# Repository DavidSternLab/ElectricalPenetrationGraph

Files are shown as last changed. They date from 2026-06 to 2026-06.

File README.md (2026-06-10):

# EPG Rig Redesign

An open, modern redesign of the Electrical Penetration Graph (EPG) recording rig —
new hardware, firmware, and software — to replace the commercial **Giga-8dd**
(EPG Systems EU / W.F. Tjallingii). Used to record stylet-penetration / feeding
behavior of the pea aphid *Acyrthosiphon pisum*.

## Goals

1. **Improve temporal resolution** of sampling (original: 14-bit ADC @ 100 Hz default).
2. **Reduce production cost.**
3. **Simplify construction.**
4. **Automate voltage-drift correction** — the electrode-potential drift currently
   corrected by hand via the supplied voltage (Vs). An auto-detect/correct in firmware/software.
5. **Cross-platform software** — original Stylet+ is Windows-only and needs custom
   USB/COM/ActiveX drivers.

## Status

Early design phase — working through architecture decisions interactively.
See [docs/design-log.md](docs/design-log.md) for locked decisions and rationale.

## Document index

- [docs/design-log.md](docs/design-log.md) — decision log (what's locked + why).
- [docs/system-architecture.md](docs/system-architecture.md) — consolidated block diagram
  + signal chain as decided so far.
- [docs/noise-bandwidth-budget.md](docs/noise-bandwidth-budget.md) — quantitative noise &
  bandwidth analysis → gain, ADC, and the layout-critical input-capacitance spec.
- [docs/protocol-and-data-format.md](docs/protocol-and-data-format.md) — USB device↔host
  protocol + HDF5 recording format (draft v0.1).
- [docs/original-circuit-reference.md](docs/original-circuit-reference.md) — facts
  extracted from the Giga-8dd manuals (the circuit we're modernizing).
- [docs/conversation-log.md](docs/conversation-log.md) — chronological narrative of
  the design discussions.

## Folders

- `docs/` — design docs and decision records.
- `hardware/` — [single-channel-schematic.md](hardware/single-channel-schematic.md) (draft v0.1,
  SPICE-verified), [pcb-layout.md](hardware/pcb-layout.md) (layout spec / hand-off);
  `hardware/sim/` ngspice netlist; `hardware/netlist/` (ERC-checked netlist + generated
  `single_channel.kicad_sch` with footprints + SVG/PDF); `hardware/pcb/` (pre-placed
  `single_channel.kicad_pcb`, custom `.kicad_dru`, board render).
- `firmware/` — RP2040 firmware: portable C protocol (host-tested + interop-verified vs the
  Python codec) + Arduino app skeleton.
- `firmware/` — MCU firmware (to come).
- `software/` — cross-platform acquisition + analysis app, Python/pyqtgraph (to come).

## Source material

Original vendor documentation lives one level up in `../Giga_rig_manuals/`
(start with `Measuring principles.pdf`; differential probe circuit is Appendix 5 /
Fig 13B of `Manual-Giga-8dd 20.pdf`). The original Windows software in
`../original_rig_software/` is distributed only as `.exe` installers, so the Stylet+
data file format is not recoverable from it — we will define our own open format.

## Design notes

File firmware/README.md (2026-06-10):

# EPG rig — RP2040 firmware

Device-side firmware. The protocol layer is **portable C, shared with the host and
unit-tested on this machine**; the RP2040 application (USB CDC + ADC/DAC/relay drivers +
Vs servo) sits on top.

```
firmware/
  proto/         epg_proto.{h,c}   portable protocol codec (COBS+CRC, builders, parser)
  test/          test_proto.c + interop_test.py + Makefile   (host-compiled, runnable now)
  src/           RP2040 app: main.cpp, ads131m08.{h,cpp}, dac8568.{h,cpp}, board.h
  platformio.ini build/flash config (arduino-pico / earlephilhower core)
```

## Status
- **`proto/` + `test/`: built and verified on the host.** `make check` runs the C
  selftest; `make interop` proves the C codec and the Python host codec
  (`software/epgrig`) are **byte-for-byte compatible** in both directions. So when this
  firmware runs, it talks to the existing host GUI unchanged.
- **`src/`: a coherent skeleton, NOT yet hardware-tested.** The ADS131M08/DAC8568 register
  sequences and the relay/servo scaling are marked `TODO: verify vs datasheet`. It will not
  have been compiled in this environment (needs the RP2040 toolchain / PlatformIO).

## Protocol tests (run now, no hardware)
```bash
cd test
make check       # C selftest: COBS / CRC / i24 / frame / parser-resync
make interop     # cross-language: C <-> Python wire compatibility
```

## Build & flash the firmware (with hardware)
```bash
# install PlatformIO (pip install platformio), then:
pio run                 # compile
pio run -t upload       # flash a Pico/RP2040 over USB
pio device monitor      # (optional) serial monitor
```
Then point the host app at the serial port (replace the mock with a pyserial transport).

## Main loop (src/main.cpp)
On ADC **DRDY**: read 8 channels → run the keep-in-range **Vs servo** (D11) → append to the
current block. Every `BLOCK_MS` (default 50 ms) a **SAMPLES** frame is flushed. Host commands
(GET_INFO / CONFIGURE / START / STOP / SET_VS / SET_RI / CAL_PULSE / SERVO / PING) are parsed
from USB; **every state change emits a sample-stamped EVENT**, so recordings stay
reconstructable exactly as the format (D14) requires.

## To finish (hardware bring-up)
- ADS131M08 register init (CLOCK/MODE/GAIN/OSR for the selected rate) + CRC handling.
- DAC8568 reference-enable + Vs code↔volts calibration; servo step gain.
- 74HC595 latching-relay set/reset pulse for Ri (1 GΩ/10 TΩ) per channel.
- Pin map in `board.h` vs the actual PCB.

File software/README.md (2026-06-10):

# epgrig — host software (Python)

Cross-platform acquisition + analysis for the redesigned EPG rig. Implements the
device↔host protocol and HDF5 recording format in [../docs/protocol-and-data-format.md](../docs/protocol-and-data-format.md),
and ships an **in-process mock device** so the entire pipeline runs and is tested
**before any hardware exists**.

## Layout
```
epgrig/
  protocol.py     COBS+CRC framing + message codecs   (pure stdlib — always importable)
  mock_device.py  synthetic device: aphid-like waveforms, electrode drift, Vs servo
  acquisition.py  parse device frames -> recorder + live callbacks (transport-agnostic)
  recorder.py     incremental crash-safe HDF5 writer
  reader.py       HDF5 reader + signal reconstruction (codes->volts, applied-Vs)
  dsp.py          display-side detrend (high-pass) — view only, never recorded
  gui.py          live pyqtgraph display (optional Qt)
scripts/
  record_mock.py  headless end-to-end demo: mock -> frames -> HDF5 -> reconstruct
  run_gui.py      launch the live GUI against the mock
tests/            protocol + pipeline tests (run with no hardware)
```

## Quick start
```bash
pip install -r requirements.txt          # numpy + h5py minimum; Qt only for the GUI

# headless end-to-end (no hardware, no Qt):
python scripts/record_mock.py /tmp/epg.h5 --seconds 30 --rate 1000

# tests:
python tests/test_protocol.py            # pure stdlib
python tests/test_pipeline.py            # needs numpy + h5py
# (or: python -m pytest)

# live GUI against the mock (needs pyqtgraph + a Qt binding):
python scripts/run_gui.py --rate 1000
```

## Design notes
- **Protocol layer is dependency-free** (stdlib only) so framing is trivially testable and
  portable; numpy/h5py are only needed for the data path, Qt only for the GUI.
- **Reconstructability:** recordings store raw 24-bit codes + a timestamped event log; the
  reader recovers input-referred volts and the applied-Vs trace, so the true signal is
  recoverable even though the keep-in-range servo nudges Vs during recording.
- **Real hardware later** drops in behind the same protocol: replace the mock's byte stream
  with a `pyserial` port (USB CDC). Nothing else changes.

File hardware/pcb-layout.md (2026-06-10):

# PCB layout specification — single-channel probe-head daughtercard

**Hand-off to the KiCad layout engineer.** The electrical design is fixed and verified
(schematic `netlist/single_channel.kicad_sch` with footprints; SPICE in `sim/`; ERC clean).
This board is a **femtoampere electrometer front end** — *layout is the design*. The rules
below are not style preferences; violating the input-node ones will sink the instrument's
performance. Do **not** autoroute the input section.

## What's provided vs. what you do
- **Provided:** schematic with footprints assigned; a starting board `pcb/single_channel.kicad_pcb`
  (23 footprints pre-placed with the intended signal flow, 60×40 mm outline, 4 layers) and a
  `pcb/single_channel.kicad_dru` with custom rules.
- **You do:** *Update PCB from Schematic* (pulls nets/ratsnest — the schematic carries
  footprints), refine placement (the starting board has ~41 courtyard/silk/edge DRC items
  from tight auto-placement — spread/rotate to clear), implement the guard scheme below,
  route, and get a clean DRC. Replace the PLACEHOLDER footprints (J2 Lemo/ODU, K1 latching
  reed relay, optionally U3 exact LFCSP) with the real vendor footprints.

## Board & stackup
- Small daughtercard, ~50–60 × 35–40 mm (refine to fit the probe-head enclosure + BNC + Lemo).
- **4-layer**, suggested: `L1 Signal / L2 Ground / L3 Power(±5) / L4 Signal`.
- **Exception (critical):** *no ground or power copper under the high-impedance input node*
  (see below) — pour reliefs / keep-outs there on all layers.

## The make-or-break input section (node M = J1→A1.INP; RI_MID; A2.INP/S)
This is the ≤1 pF, sub-fA-leakage region (validated: f₋₃dB = 1/(2π·(Rbe‖Ri)·Cin), so Cin
sets bandwidth — D13/D16).
1. **Minimize Cin:** A1 immediately adjacent to J1; M trace as short and thin as possible;
   **no vias** on M; **no copper plane under M** on any layer (cut out / keep-out). Keep RI
   and K1 contacts right at the node.
2. **Guard ring:** surround M (and the A1 +input pin/trace, RI, K1 contacts) with a guard
   trace driven by **A1.GUARD**; do the same for A2.INP using **A2.GUARD**. The guard
   follows the high-Z trace on the component layer *and* is mirrored on the layer beneath
   (guard "box"), connected only to the GUARD pin — never to ground. This bootstraps stray
   capacitance and intercepts surface-leakage currents.
3. **Surface leakage:** consider a **milled slot/moat** in the PCB around the M node to break
   surface conduction; specify **solder-mask opening** over the guard region and **conformal
   coat** (or PTFE) after a thorough clean. Use **no-clean-free** assembly or wash + bake;
   the input area must be contamination-free (fingerprints = picoamps).
4. **The ADA4530-1 guard pins** (A1, A2) must connect *only* to their guard rings.

## Net classes (set in Board Setup → Net Classes)
| Class | Nets | Trace | Clearance | Notes |
|---|---|---|---|---|
| **HighZ** | M, RI_MID | thin (~0.2 mm), no via | ≥0.6 mm to other copper | guarded; no plane under |
| **Guard** | GUARD1, GUARD2 | ~0.3 mm | hugs HighZ | from GUARD pins only |
| Power | P5V, N5V | ≥0.4 mm | 0.2 mm | decouple at each amp (C1–C6) |
| Signal | A1_OUT, A2_OUT, FDA_*, VOCM | 0.25 mm | 0.2 mm | keep FDA gain net symmetric |
| Diff | LINE_A, LINE_B | 0.25 mm, matched | 0.2 mm | route as a pair to J2 |
| default | rest | 0.25 mm | 0.2 mm | |

## Placement intent (as pre-placed)
Left→right flow: **J1 (BNC, input edge) → A1 → [K1, RI] input cluster → A2 → U3 (FDA) +
gain net (RG/RF) → RO1/RO2 → J2 (Lemo, output edge)**. VOCM divider (RV1/RV2/CV) and the
relay driver U4 near their loads. Decoupling C1–C6 hard against the amp power pins.

## Grounding / shielding
- One solid analog ground (L2), **relieved under the input node**. Tie to the probe-head
  shield/enclosure and to chassis/Faraday-cage ground via J2 (AGND + SHLD shell).
- The daughtercard carries **no digital/clocks** (D6) — ±5 V + filtered Vs + one slow Ri
  logic line arrive over the Lemo; the relay set/reset pulse is generated locally (U4).
- Differential pair LINE_A/LINE_B: route together, length-matched, over ground.

## Differential output + ADC interface (motherboard side, FYI)
LINE_A/B (FDA outputs through RO1/RO2) drive the cable into the ADS131M08 differential
input; common-mode = VOCM ≈ 1.67 V (RV1/RV2 divider). Anti-aliasing is handled by the Σ-Δ
decimation filter (no analog AA filter; D13).

## Acceptance
- DRC clean against `single_channel.kicad_dru`.
- Guard rings continuous and connected only to GUARD pins; no copper under M; no vias on M.
- Real footprints substituted for the three PLACEHOLDERs.

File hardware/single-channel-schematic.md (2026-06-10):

# Single-channel schematic (draft v0.1)

First schematic-level design for one EPG channel, implementing the locked decisions
(D1–D13). Split across the **probe-head daughtercard** (one per channel, in the Faraday
cage) and the shared **motherboard** (outside the cage). The analog chain's gain, the
Ohm's-law divider, and the front-end bandwidth are **verified by SPICE**
(`sim/single_channel.cir`); see §6.

## 1. Block diagram

```
            DAUGHTERCARD (probe head, in cage)                       MOTHERBOARD (outside cage)
  insect ─BNC(J1)─┬───────────────┐ M
                  │            +  ╱│ A1 = ADA4530-1
                  │   ┌────────┤+  │── a1 ──┐ (unity follower, GUARD-ringed)
                  │   │         ╲ │          │
              Cin═╪═  │          ─┘          │   ┌─ Rg ─┐         FDA = ADA4940-1
            (≤1pF)│   │  [Ri 1GΩ]            ├──[Rg]──┤−  ╲___ OUT+ ─Riso─�────►║  A B ►► ADS131M08
                  │   │  + K1(reed)          │        │FDA │              ║      AINxP/AINxN
                  │   └──/ ──────┐ S         │   ┌────┤+  ╱‾‾‾ OUT− ─Riso─�────►║   (24-bit, 8-ch,
  plant ─────── earth/GND        │           │   │    └ VOCM=ADC Vcm        ║    simul-sampling,
                  ┌──────────────┘           │   │                          ║    differential)
            Vs_in ┤ (filtered)   +  ╱│ A2     │  [Rf]                         SPI │ DRDY
                  └──────────────┤+  │── a2 ──┘   │                              ▼
                                  ╲ │            (a2 also feeds FDA + via Rg)  RP2040 ──USB-CDC──► host
                                   ─┘ A2=ADA4530-1                              │ SPI
                                                                                ▼
   Vs_in ◄── LPF(~10Hz) ◄── scale/offset(±0.5V) ◄── DAC8568 ◄────────────── (Vs servo + cal pulse)
   Ri_ctrl ◄── latching-relay driver ◄── GPIO ─────────────────────────────  (1GΩ/10TΩ select)
   Power: USB 5V ─► LM27762 ─► ±5V analog (clean) ;  ─► 3.3V LDO ─► digital
```

## 2. Analog signal chain (daughtercard)

1. **Insect electrode → node M** via BNC (J1). M is the high-impedance measuring point;
   guard ring driven by A1's GUARD pin; keep the trace tiny (see §5).
2. **A1, A2 = ADA4530-1** femtoampere electrometer op-amps, unity-gain followers. A1 senses
   M (insect); A2 senses S (the Vs side of Ri). Both present ~fA load so they don't corrupt
   the sub-nA current through Ri. (Two electrometer amps/channel — D8.)
3. **Ri network between M and S:** Ri = 1 GΩ precision resistor in series with **K1**, a
   latching reed relay. Closed → Ri = 1 GΩ (R+emf mode). Open → the only path left is the
   amps' intrinsic input resistance (~10 TΩ) → pure-emf mode (D2). Reed relay for true
   open isolation; latching so it's quiet during recording.
4. **Vs_in → node S:** the filtered, scaled supplied voltage from the motherboard DAC is
   applied at S (the "former grounded side" of Ri — differential config, D7). The −50 mV
   **cal pulse rides on Vs_in** (firmware step), so no extra hardware (D14).
5. **FDA = ADA4940-1:** takes (a1 − a2) differentially through gain-set resistors and
   produces a differential pair OUT+/OUT− with common-mode = the ADC's input Vcm. This one
   stage provides **both** the gain and the differential cable drive (D6). Gain
   `G = Rf/Rg`; with **Rg = 1.00 kΩ, Rf = 8.06 kΩ → G ≈ 8** (D13: maps ±150 mV Vi to the
   ±1.2 V ADC range). Series isolation resistors Riso (~24 Ω) at each output drive the cable.

## 3. Motherboard slice

- **ADS131M08** (8-ch, 24-bit, simultaneous-sampling Σ-Δ): the channel's differential pair
  (optionally through a small RC: ~33 Ω + 2.2 nF differential) → AINxP/AINxN. The Σ-Δ
  decimation filter handles anti-aliasing (D13) — the RC is just for charge-kickback. SPI +
  DRDY to RP2040; clean CLKIN oscillator.
- **Vs path:** RP2040 → SPI → **DAC8568** (16-bit) → scale/offset op-amp (**OPA2188**-class)
  to ±0.5 V → low-pass (~10 Hz, e.g. 16 kΩ + 1 µF; the servo is slow so heavy filtering is
  fine and keeps noise off the cable) → Vs_in on the cable.
- **Ri select:** RP2040 GPIO → on-card **latching-relay driver** (a logic transition emits a
  set/reset pulse to K1) via the Ri_ctrl line. Energized only on change → no coil
  current/field near the node during recording.
- **RP2040:** USB-CDC to host; SPI to ADC + DAC; GPIO for relay. Runs the Vs servo (D11).
- **Power:** USB 5 V → **LM27762** → clean ±5 V analog (LDO-quiet) for the op-amps; **3.3 V
  LDO** for digital (RP2040, ADC/DAC digital). Within the USB current budget.

## 4. Component table (one channel + shared motherboard)

| Ref | Part | Value / note | Where |
|---|---|---|---|
| A1, A2 | ADA4530-1ARZ | electrometer, <20 fA bias, guard buffer | daughtercard |
| FDA | ADA4940-1 | fully-differential amp / ADC + cable driver | daughtercard |
| Ri | precision Gigaohm R (Ohmite RX/Vishay VHM) | 1 GΩ, 0.1% | daughtercard |
| K1 | latching reed relay (Coto/Pickering) | >10¹⁴ Ω open | daughtercard |
| Rg, Rf | thin-film 0.1% | 1.00 kΩ, 8.06 kΩ (G≈8) | daughtercard |
| Riso | thin-film | ~24 Ω ×2 | daughtercard |
| J2 | Lemo/ODU push-pull 8-pin | A,B,Vs_in,+5,−5,AGND,Ri_ctrl,shield | daughtercard |
| ADC | ADS131M08 | 8-ch 24-bit Σ-Δ | motherboard (shared) |
| DAC | DAC8568 | 8-ch 16-bit | motherboard (shared) |
| Vs amp | OPA2188 (or similar precision) | scale/offset to ±0.5 V | motherboard |
| MCU | RP2040 | USB-CDC, SPI | motherboard (shared) |
| PSU | LM27762 + 3.3 V LDO | ±5 V analog, 3.3 V digital | motherboard (shared) |

## 5. Layout-critical (the make-or-break items)

- **Cin ≤ ~1 pF at node M.** The sim shows f₋₃dB scales as `1/Cin`; 1 pF → ~318 Hz, 2 pF →
  ~159 Hz. Short M trace, minimal copper, A1 close to J1.
- **Guard ring** around M (and the Ri/relay node) driven by ADA4530-1 GUARD; **conformal
  coat** the input region; keep flux/contamination off (sub-fA leakage).
- Star/seperated analog vs digital grounds; the daughtercard carries **no clocks/digital**.

## 6. Verification (SPICE — `sim/single_channel.cir`, ngspice)

Ideal-op-amp behavioral model (checks topology + values; real noise/bias come from the parts):

| Check | Expected | Simulated |
|---|---|---|
| Ohm's-law divider Vi (Vbio=1 mV, Rbe=Ri=1 GΩ) | 0.500 mV | **0.500 mV** |
| Differential output Vout = G·Vi (G=8) | 4.00 mV | **4.00 mV** |
| Front-end f₋₃dB (Rbe‖Ri = 0.5 GΩ, Cin = 1 pF) | 318.3 Hz | **318.3 Hz** |

The bandwidth result confirms the noise-bandwidth budget (D13): at 1 GΩ the analog band is
~few-hundred Hz, capacitance-limited — so 1 kHz+ sampling oversamples it (good for edges /
anti-alias), and Cin is the dominant lever.

## 7. Open items → next
- KiCad schematic capture + symbols/footprints from this spec.
- Finalize FDA supply rail + VOCM source (match ADC input Vcm ≈ AVDD/2); ADA4940 vs lower-noise alt.
- Latching-relay driver sub-circuit (single logic line → set/reset pulse).
- Exact ADC anti-alias/charge-kickback RC; CLKIN oscillator choice.
- Vs scale/offset stage exact values + filter corner; current budget for USB.
- RP2040 firmware skeleton speaking the existing protocol (talks to the current host GUI).

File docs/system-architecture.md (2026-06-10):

# System architecture (working draft)

Consolidated view of the design as decided so far (see [design-log.md](design-log.md)
D1–D10). Two physical units: **probe heads** (one per channel, inside the Faraday cage)
and a single **motherboard** (all digital, outside the cage), joined by shielded
multi-conductor cables with Lemo/ODU connectors.

## Block diagram

```
  ┌───────────── PROBE HEAD ×8 (inside Faraday cage) ──────────────┐
  │                                                                │
  insect ─BNC─►(+)┌────────────┐                                   │
                  │ ADA4530-1  │A1 (electrometer buffer, guarded)  │
                  └─────┬──────┘                                   │
                        │   ┌──────[ Ri ]──────┐                   │
                        │   │ 1GΩ via latching  │                  │
                        ├───┤ reed relay (closed)│                 │
                        │   │ 10TΩ = amp intrinsic│                │
                        │   │      (relay open)   │                │
                  ┌─────┴──────┐  └──────────────┘                 │
                  │ ADA4530-1  │A2 (electrometer buffer)           │
                  └─────┬──────┘  ▲                                │
                        │         └─ Vs (filtered, from m'board)   │
                  ┌─────▼──────┐                                   │
                  │ diff amp   │  fixed gain ≥50× → Vsig           │
                  │ (amp 3)    │                                   │
                  └─────┬──────┘                                   │
                  ┌─────┴───────┐                                  │
            ┌─────┤ buf +1      ├──── line A ─┐                    │
   Vsig ────┤     └─────────────┘             │ differential       │
            │     ┌─────────────┐             │ pair (twisted)     │
            └─────┤ inv −1      ├──── line B ─┘                    │
                  └─────────────┘                                  │
  plant ─────────────────────────────────── earth/GND             │
  └─────────────────────── Lemo/ODU 8-pin + shielded cable ───────┘
        carries: A, B, Vs, +V, −V, AGND, Ri-switch ctrl, (shield)

  ┌──────────────── MOTHERBOARD (outside cage) ────────────────────┐
  │  A/B ►► ADS131M08  (8-ch, 24-bit, simul-sampling Σ-Δ,          │
  │           differential inputs = the diff receiver) ──SPI──┐    │
  │                                                           ▼    │
  │  Vs out ◄── LPF ◄── scale/offset ◄── DAC8568 ◄──SPI──► RP2040 ─┼─USB-CDC─► host
  │  Ri ctrl ◄── relay driver ◄─────────────────────────► (servo + │
  │                                                  streaming)    │
  │  Power: USB 5V ─► LM27762 ─► clean ±V analog                   │
  │                   └──────► 3.3V LDO ─► digital                 │
  └────────────────────────────────────────────────────────────────┘
```

## Signal chain (per channel)

1. **Insect electrode** (gold wire) → BNC → ADA4530-1 buffer **A1** (the critical
   high-impedance, guarded node).
2. **Ri** between A1 and A2 inputs: 1 GΩ resistor in series with a **latching reed relay**
   (closed = 1 GΩ R+emf mode; open = 10 TΩ pure-emf mode, set by the amps' intrinsic input
   resistance).
3. **A2** buffers the Vs side of Ri; **Vs** (slow, filtered) is applied here from the
   motherboard DAC.
4. **Difference amp (A3)**, fixed gain ≥50× → single-ended `Vsig`.
5. **Differential cable drive:** a unity buffer (line A) + an inverter (line B) present
   `Vsig` differentially to the cable. (These are ordinary precision op-amps — low-impedance
   side.)
6. **Cable** (Lemo/ODU) → motherboard.
7. **ADS131M08** differential input does the A−B subtraction (rejecting common-mode cable
   noise) and digitizes 24-bit, all 8 channels simultaneously.
8. **RP2040** streams samples over USB-CDC and runs the Vs servo + Ri-switch control.

## Key behaviors

- **Plant = earth ground** (differential primary circuit, D7/original differential design):
  enables multiple insects per plant and field use; adjustments are on the insect side.
- **Cal pulse** = firmware-commanded −50 mV step on the Vs line (no dedicated hardware).
- **Auto-drift correction** = slow Vs servo toward a user-set target baseline, every change
  logged (design TBD — next topic).
- **Only per-channel adjustment = Vs** (gain is fixed; mostly automated).

## Open / to-be-detailed
- Vs servo loop (sense, rate, target, logging, manual override).
- Noise budget → final fixed-gain value; ADS131M08 vs AD7768-8.
- Bipolar-supply detail + USB current budget; clean ADC clock.
- Mechanical: probe-head enclosure (shielded), guard-ring layout, conformal coating.
- Device↔host protocol + open data file format.

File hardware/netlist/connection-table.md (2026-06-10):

# Single-channel daughtercard — connection table

_Generated by `channel_netlist.py` (ERC-checked). Pin numbers bind at KiCad symbol assignment._

## Components

| Ref | Part | Footprint | Pins |
|---|---|---|---|
| J1 | BNC (insect electrode) | Connector_Coaxial:BNC_Amphenol_031-5539_Vertical | SIG, SHLD |
| A1 | ADA4530-1 (follower, insect) | Package_SO:SOIC-8_3.9x4.9mm_P1.27mm | INP, INN, OUT, VPOS, VNEG, GUARD |
| A2 | ADA4530-1 (follower, Vs side) | Package_SO:SOIC-8_3.9x4.9mm_P1.27mm | INP, INN, OUT, VPOS, VNEG, GUARD |
| K1 | latching reed relay (Ri sw) | Relay_THT:Relay_1-Form-A_Schrack-RYII_RM5mm | P1, P2, CP, CN |
| RI | 1 GOhm precision resistor | Resistor_SMD:R_1206_3216Metric | A, B |
| U3 | ADA4940-1 FDA (gain + diff drv) | Package_DFN_QFN:HVQFN-16-1EP_3x3mm_P0.5mm_EP1.5x1.5mm | INP, INN, OUTP, OUTN, VOCM, VPOS, VNEG, PD |
| RG1 | gain input R (1.00k) | Resistor_SMD:R_0603_1608Metric | A, B |
| RG2 | gain input R (1.00k) | Resistor_SMD:R_0603_1608Metric | A, B |
| RF1 | feedback R (8.06k) | Resistor_SMD:R_0603_1608Metric | A, B |
| RF2 | feedback R (8.06k) | Resistor_SMD:R_0603_1608Metric | A, B |
| RO1 | output iso R (24R) | Resistor_SMD:R_0603_1608Metric | A, B |
| RO2 | output iso R (24R) | Resistor_SMD:R_0603_1608Metric | A, B |
| RV1 | VOCM divider top (2.00k) | Resistor_SMD:R_0603_1608Metric | A, B |
| RV2 | VOCM divider bot (1.00k) | Resistor_SMD:R_0603_1608Metric | A, B |
| CV | VOCM bypass cap | Capacitor_SMD:C_0603_1608Metric | A, B |
| C1 | A1 +rail decoupling | Capacitor_SMD:C_0603_1608Metric | A, B |
| C2 | A1 -rail decoupling | Capacitor_SMD:C_0603_1608Metric | A, B |
| C3 | A2 +rail decoupling | Capacitor_SMD:C_0603_1608Metric | A, B |
| C4 | A2 -rail decoupling | Capacitor_SMD:C_0603_1608Metric | A, B |
| C5 | U3 +rail decoupling | Capacitor_SMD:C_0603_1608Metric | A, B |
| C6 | U3 -rail decoupling | Capacitor_SMD:C_0603_1608Metric | A, B |
| U4 | latching-relay driver (H-bridge) | Package_TO_SOT_SMD:SOT-23-6 | IN, VCC, GND, OUT1, OUT2 |
| J2 | Lemo/ODU 8-pin to motherboard | Connector_PinHeader_2.54mm:PinHeader_1x08_P2.54mm_Vertical | LINE_A, LINE_B, VS_IN, P5V, N5V, AGND, RI_CTRL, SHLD |

## Nets

| Net | Connections |
|---|---|
| M | J1.SIG, A1.INP, K1.P1 |
| RI_MID | K1.P2, RI.A |
| S | RI.B, A2.INP, J2.VS_IN |
| A1_OUT | A1.OUT, A1.INN, RG1.A |
| A2_OUT | A2.OUT, A2.INN, RG2.A |
| FDA_INN | RG1.B, RF1.A, U3.INN |
| FDA_INP | RG2.B, RF2.A, U3.INP |
| FDA_OUTP | U3.OUTP, RF1.B, RO1.A |
| FDA_OUTN | U3.OUTN, RF2.B, RO2.A |
| LINE_A | RO1.B, J2.LINE_A |
| LINE_B | RO2.B, J2.LINE_B |
| VOCM | U3.VOCM, RV1.B, RV2.A, CV.A |
| RI_CTRL | U4.IN, J2.RI_CTRL |
| RELAY_SET | U4.OUT1, K1.CP |
| RELAY_RST | U4.OUT2, K1.CN |
| P5V | A1.VPOS, A2.VPOS, U3.VPOS, U3.PD, RV1.A, U4.VCC, C1.A, C3.A, C5.A, J2.P5V |
| N5V | A1.VNEG, A2.VNEG, U3.VNEG, C2.A, C4.A, C6.A, J2.N5V |
| AGND | J1.SHLD, RV2.B, CV.B, U4.GND, C1.B, C2.B, C3.B, C4.B, C5.B, C6.B, J2.AGND |
| SHLD | J2.SHLD |
| GUARD1 | A1.GUARD |
| GUARD2 | A2.GUARD |

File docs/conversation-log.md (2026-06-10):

# Conversation log

Chronological narrative of the design discussions. Decisions are summarized formally in
[design-log.md](design-log.md); this file captures the reasoning and Q&A as it unfolded.

---

## Session 1 — 2026-06-09 / 2026-06-10

### Kickoff
David asked whether there is enough information (including a circuit model) to redesign and
build an entire new EPG rig, with five goals: better temporal resolution, lower cost,
simpler construction, automatic voltage-drift correction, and cross-platform software
(originally suggesting Java).

Read the vendor docs (`Measuring principles.pdf`, `Manual-Giga-8dd 20.pdf` incl. Appendix 5
/ Fig 13B, waveform characteristics). Conclusion: **yes**, enough to design an improved
equivalent — the front end is a textbook 3-op-amp instrumentation amp and all critical
specs are documented (see [original-circuit-reference.md](original-circuit-reference.md)).
The remaining items are design *decisions*, not missing information. Noted the original
software is Windows-only `.exe` installers, so the data format must be redefined.

### emf-mode (1 GΩ vs 10 TΩ)
David questioned whether dropping the 10 TΩ "pure emf" mode was wise, noting the docs imply
entangled R+emf is fine for small insects. Resolved: he's right — 1 GΩ entangled mode is
the correct routine mode for aphids; pure-emf is a specialized plant-electrophysiology tool
that actually suppresses the R-components used to identify waveforms. Key technical point:
the 10 TΩ is the op-amp's *own* input resistance (not a discrete part), so keeping the
switch is nearly free. → **Decision D2: keep the switch.**

### Channel count cost (1 vs 8)
David asked if 1- vs 8-channel differs much in build/cost. Explained that engineering
effort is ~channel-count-independent (front-end block designed once; ADC/DAC are already
multichannel); only the analog front-end BOM scales. → **Decision D3: per-channel
daughtercard, design for 8, build 1 first.**

### Location of digitization
Compared central digitization (analog over cable, shared ADC — like the original) vs
per-probe digitization (ADC at each probe, digital over cable). Central wins: keeps digital
switching away from the femtoamp node, gives free channel sync, lower cost, simpler
firmware. Added a cheap enhancement — drive the cable **differentially** for common-mode
noise rejection. → **Decision D6.**

### How differential cable drive works
David asked for the mechanism. Explained common-mode rejection: send the signal as the
difference between two paired wires; coupled 50/60 Hz noise and ground offsets land equally
on both and cancel in the receiver's A−B subtraction. Implementation for us: one extra
inverting op-amp per card (on the low-impedance side, post-electrometer) makes the
complementary line; the Σ-Δ ADC's native differential input is the receiver, so no separate
receiver chip is needed. Also noted the cal pulse can ride on the Vs line as a firmware
step.

### Housekeeping
Created this `EPG_redesign/` project folder and seeded README, design-log,
original-circuit-reference, and this conversation log.

### Cable & connector scheme
Established that EPG probes are positioned individually on stands (no backplane), so each
daughtercard sits in its own probe head on a multi-conductor cable. Counted ~7 conductors +
shield per channel (signal pair, Vs, ±V, AGND, Ri-switch control). Cal pulse rides on Vs
(no extra wire); ±V sent from motherboard (no switching at the probe). David chose
**Lemo/ODU push-pull 8-pin** for the probe-to-motherboard connector (premium: locking,
shielding, durability) and **BNC** stays at the probe tip. → **Decision D7.**

### Core component selection — electrometer front end
Presented the input op-amp as the make-or-break part (two electrometer amps per channel,
both across Ri). Compared ADA4530-1 (20 fA, integrated guard buffer, ~$11) vs LMP7721
(3 fA, manual guarding, ~$4). David chose **ADA4530-1** for lowest layout risk and 10 TΩ
suitability. Ri switch recommended as a **latching reed relay** for true open isolation.
→ **Decision D8.**

### Core support ICs + gain architecture + priority guidance
Recommended motherboard chipset: ADS131M08 (24-bit 8-ch simul-sampling Σ-Δ, doubles as the
differential receiver), DAC8568 (8-ch 16-bit Vs), RP2040 MCU, LM27762 bipolar power.
**David stated a standing priority:** not very cost-sensitive — maximize sensitivity and
operational simplicity at every step (saved to memory `epg-priorities`). On gain he asked me
to decide accordingly → **fixed gain, no PGA** (simplest to operate; PGA would add noise);
sensitivity comes from 24-bit + oversampling/decimation, gain value set by a noise budget.
Chose **RP2040**. → **Decisions D9, D10.** Consolidated everything into
[system-architecture.md](system-architecture.md) (block diagram + signal chain).

### Vs auto-servo design
Worked through the servo. Established it's needed even with 24-bit (50× amplifies DC
electrode drift into volts that would rail the ADC). Proposed a two-phase design: Acquire
(auto start-up adjustment) + Track. David chose **keep-in-range only** for the track phase
(hardware moves Vs only to prevent clipping; display centered in software; all Vs changes
logged). → **Decision D11.**

### Sample rate requirement
David: wants **≥ 1000 Hz** sampling (not the original 100 Hz). Already supported by the
chipset; the real implication is the front-end −3 dB bandwidth must reach ≥ ~500 Hz at
1 GΩ, which constrains input-node capacitance / guard-ring layout (ADA4530-1 guard buffer
helps). → **Decision D12.**

### Noise & bandwidth budget (D13)
Wrote [noise-bandwidth-budget.md](noise-bandwidth-budget.md). Key results: (1) noise floor =
1 GΩ thermal noise ~30–65 µV RMS, dominating op-amp/ADC by 100×+; (2) fixed gain ≈ **8×**,
not 50×, because the ADS131M08 ±1.2 V range + 24-bit depth need little analog gain; (3)
ADS131M08 confirmed, AD7768-8 unnecessary; (4) **realistic front-end bandwidth ~150–300 Hz**
at 1 GΩ — 500 Hz needs impractical sub-pF C_in, so 1 kHz sampling oversamples a ~250 Hz band
(great for edges/anti-alias, but not 500 Hz of content); C_in≈1 pF is the make-or-break
layout spec; capacitance-neutralization footprint left as future option; (5) Σ-Δ decimation
filter removes the need for an analog anti-alias filter.

### Sample-rate reconsidered (D12 revised)
David pushed back: aphid bandwidth is genuinely unknown (100 Hz prior sampling → only <50 Hz
known); worth exploring higher but maybe 1 kHz isn't required — does 500 Hz simplify the
design? Answer: **no** — sample rate is a runtime config setting, not a hardware driver
(ADC, front end, MCU, USB, layout, firmware all identical for 500 vs 1000 vs 2000 Hz; only
Nyquist ceiling + file size differ). So D12 revised to **runtime-configurable rate, default
1 kHz**, to let real recordings reveal whether faster content exists. The independent lever
is analog bandwidth (capacitance neutralization, footprint reserved). Also clarified
"railing" = amplifier/ADC output saturating at its supply rail / clipping.

### Device↔host protocol + data format (D14)
Drafted [protocol-and-data-format.md](protocol-and-data-format.md) v0.1. USB CDC + COBS
framing + CRC; typed messages; `sample_index` master timeline; every state change emitted as
a timestamped EVENT (authoritative log). Raw 24-bit codes on the wire. HDF5 file
(`/samples`, `/events`, metadata), incremental crash-safe writes, defined reconstruction
conventions, CSV + future NWB export. This unblocks the Python software to build against the
contract in parallel with hardware.

### Python software + mock device (D15) — BUILT & TESTED
Chose to build the software first. Implemented `software/epgrig` (protocol/mock/acquisition/
recorder/reader/dsp/gui) + scripts + tests. Fixed three bugs during bring-up (COBS encoder,
an Info struct size, and over-strict test thresholds). **All 15 tests pass**; headless demo
records 30 s × 8 ch @ 1 kHz to HDF5 with 0 CRC errors and demonstrates the Vs servo +
reconstruction. The D14 protocol/format contract is now validated by real code; real
hardware will drop in behind the same protocol via pyserial. See [design-log D15](design-log.md).

### GUI bring-up feedback + real acquisition app
David ran the demo GUI: it displayed, but the detrend toggle did nothing. Cause: the
keypress handler was attached as an instance attribute (`win.keyPressEvent = ...`), which
Qt never calls (it dispatches the virtual to the class method). Replaced the hidden keypress
with on-screen controls. Rebuilt `gui.py` into a real acquisition window: live plots with a
working **Detrend** checkbox + cutoff, **Record/Stop**, folder/filename/operator/experiment
fields, status (state/elapsed/samples/clip/CRC), and **Add marker** (writes EV_COMMENT).
Added recorder support for **starting mid-stream**: the file stores `device_start_sample_index`
and events are written file-relative so reconstruction stays correct (new test
`test_midstream_recording_offsets_are_file_relative`). 16 tests pass; GUI parse-checked
(Qt still not installed here, so not launched by me — David runs it).

### Sample-rate toggle + per-channel controls + GitHub repo
David: GUI looks good; add a sample-rate toggle; wire up per-channel controls; create a
GitHub repo `ElectricalPenetrationGraph` under github.com/DavidSternLab.
- **Sample-rate selector** added to the GUI (combo from `Info.supported_rates`; reconfigures
  buffers live; disabled while recording).
- **Per-channel controls** wired end-to-end through the mock: Vs (mV→DAC, SET_VS), servo mode
  off/acquire/track (SERVO), Ri 1 GΩ/10 TΩ (SET_RI), cal pulse (CAL_PULSE). The mock now
  *acts* on these and emits the corresponding logged events; cal pulse injects −50 mV and
  auto-offs; servo respects the mode. New `tests/test_commands.py` (3 tests). **19 tests pass.**
- **Git:** initialized a local repo rooted at `EPG_redesign/` (excludes the copyrighted
  vendor PDFs/installers in sibling folders) and made the initial commit. **Could NOT create
  or push the GitHub remote** — no `gh`, token, or SSH key in this environment; that step
  needs David's GitHub auth. Push instructions provided.

### GitHub repo pushed
Created + pushed **public** repo github.com/DavidSternLab/ElectricalPenetrationGraph (account
`dstern`). First `gh repo create --push` made the repo but failed to push (gh set to SSH, no
trusted key); fixed by `gh auth setup-git` + switching origin to HTTPS. 3 commits on `main`.

### Single-channel schematic v0.1 (D16) — SPICE-verified
Built `hardware/single-channel-schematic.md` and `hardware/sim/single_channel.cir`. Topology:
ADA4530-1 ×2 electrometer followers across Ri (1 GΩ + latching reed relay), FDA (ADA4940-1)
giving gain≈8 + the differential cable drive in one stage; motherboard = ADS131M08 / DAC8568
/ RP2040 / LM27762. Installed ngspice (brew) and simulated: divider Vi=0.500 mV ✓, gain
Vout=4.00 mV (8×) ✓, **f₋₃dB=318.3 Hz = analytic to 100%** → confirms the D13 bandwidth
budget and that Cin≤~1 pF is the key layout lever.

### RP2040 firmware skeleton (D17)
Built `firmware/`: protocol re-implemented in **portable C** (`proto/epg_proto.{h,c}`) and the
RP2040 app skeleton (`src/main.cpp` + ADS131M08/DAC8568 drivers + board.h + platformio.ini).
Key verification: a host-compiled C selftest plus a **cross-language interop test** (C builds
frames → Python parses, and vice-versa) — **byte-for-byte compatible both ways**, so the
firmware speaks exactly what the host GUI expects. ADC/DAC register details + relay/servo
scaling are TODO (datasheet/bring-up); src/ not compiled here. All host tests still pass.

### Netlist + KiCad schematic capture (D18)
David installed KiCad (10.0.3) → enables `kicad-cli` validation. Built `hardware/netlist/`:
`channel_netlist.py` (23 comp / 71 pins / 21 nets + ERC checker, 0 err/0 warn) →
`gen_kicad_sch.py` emits `single_channel.kicad_sch` (box symbols + global-label-per-pin).
Validated via kicad-cli: upgrade OK; ERC clean except benign warnings (embedded-symbol
"library not configured" ×23, intentional single-node nets ×3); **zero connectivity errors**.
Rendered SVG/PDF and visually confirmed all parts/pins/labels. Boxes + no footprints =
first capture; swap to library symbols + footprints during manual cleanup.

### PCB layout groundwork + hand-off (D19)
David will recruit a KiCad layout engineer to finish — so I did the verifiable groundwork:
assigned footprints (in netlist + schematic Footprint properties; 3 PLACEHOLDERs noted),
generated a pre-placed `pcb/single_channel.kicad_pcb` via the pcbnew API (electrometer-aware
placement, 60×40 mm, 4 layers; kicad-cli DRC = 0 structural errors, 40 placement-refinement
items), wrote `pcb-layout.md` (stackup, guard rings, Cin≤1 pF rules, net classes, grounding)
and `pcb/single_channel.kicad_dru` (custom rules, parse-validated). Rendered board_top.svg.

### Hand-off state
Layout engineer's tasks: Update-PCB-from-Schematic → refine placement → guard scheme → route
→ swap PLACEHOLDER footprints → DRC clean. Remaining elsewhere: firmware hardware bring-up;
finalize FDA supply/VOCM + Vs stage + USB budget; probe-head mechanical; software niceties.

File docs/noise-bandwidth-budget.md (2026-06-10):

# Noise & bandwidth budget

Quantitative analysis that converts the architecture into component values. Numbers from
`scripts`-free hand calc (k=1.38e-23 J/K, T=300 K). **Headline: at Ri=1 GΩ the system is
dominated by two pieces of fundamental physics — the resistor's thermal noise and the
Ri·C_in bandwidth — and both are properties of the 1 GΩ choice, not of our electronics.
Our job is to sit comfortably under them, which is easy.**

## 1. Signal levels

- Original full-scale input ≈ ±117 mV (±5.85 V output ÷ 50×). Cal pulse = −50 mV input.
- After Vs cancels the DC electrode potential, the residual EPG swing is the signal itself:
  largest features ≈ ±100–150 mV; fine detail down to µV.
- Design target: **full-scale input ≈ ±150 mV** (covers large features + servo deadband).

## 2. Bandwidth — the honest constraint

Front-end −3 dB corner `f_c = 1/(2π · R_node · C_in)`, where `R_node = Rbe ‖ Ri`
(≈ 0.5 GΩ when an aphid is probing with Rbe≈Ri≈1 GΩ; = 1 GΩ when not probing).

| C_in | f_c @ R=0.5 GΩ (probing) | f_c @ R=1 GΩ |
|---|---|---|
| 0.5 pF | 637 Hz | 318 Hz |
| 1 pF | 318 Hz | 159 Hz |
| 2 pF | 159 Hz | 80 Hz |
| 5 pF | 64 Hz | 32 Hz |

To reach **500 Hz** you'd need C_in ≈ 0.32–0.64 pF — below the op-amp's own input
capacitance plus the relay and board stray. **Realistically, with aggressive guarding
(C_in ≈ 1 pF) the achievable analog bandwidth at 1 GΩ is ~150–300 Hz** (probing), ~80–160 Hz
when not probing. This is *already better than the original* (~100 Hz) but it is **not**
500 Hz.

**Implication for the 1 kHz sampling target:** sampling at ≥1 kHz is correct and worthwhile
— it oversamples the ~200–300 Hz analog band, which (a) captures the *edges* of potential
drops and the cal pulse far better than 100 Hz, (b) gives clean anti-aliasing margin, and
(c) enables oversample+decimate for SNR. But understand it as **10× better time resolution
of a ~200–300 Hz-bandwidth signal**, not 500 Hz of new spectral content. The aphid waveform
content of interest is < ~100 Hz, so this is comfortable.

**If more analog bandwidth is ever needed:** capacitance neutralization (active positive-C
feedback bootstrapping C_in, as patch-clamp amps do) can extend f_c. Recommend leaving a
populate-later footprint for it rather than building it in v1.

The 10 TΩ emf-mode is inherently sub-Hz and stays low-rate by nature (fine — it's for slow
plant potentials).

## 3. Noise — the resistor wins

Johnson noise density `e = √(4kT·R)`:
- R_node = 0.5 GΩ (aphid probing): **2.88 µV/√Hz**
- R_node = 1 GΩ (not probing): **4.07 µV/√Hz**

Integrated over the band:

| Band | R=0.5 GΩ | R=1 GΩ |
|---|---|---|
| 100 Hz | 28.8 µV RMS | 40.7 µV RMS |
| 250 Hz | 45.5 µV RMS | 64.4 µV RMS |

So the **input-referred noise floor is ~30–65 µV RMS, set entirely by the 1 GΩ resistor's
thermal noise.** Compare the other sources:
- **ADA4530-1 voltage noise** (~tens of nV/√Hz) over 250 Hz → ~1 µV — negligible.
- **ADA4530-1 current noise** (~0.07 fA/√Hz) × R_node → ~35 nV/√Hz → sub-µV — negligible.
- **ADC noise** input-referred (see §4) → ~0.3–0.4 µV — negligible (100×+ below).

This is fundamental to the 1 GΩ choice (which we keep for the science) — the original lives
at the same floor. Note: **decimation/averaging does not reduce the in-band resistor noise**
(it's already band-limited); it reduces only the wideband ADC/quantization noise and buys
anti-alias margin. Fine detail below ~30 µV is thermally limited, not electronics-limited.

## 4. Gain — much lower than the original (≈8×, not 50×)

ADS131M08 input range = ±1.2 V (internal 1.2 V ref). To map ±150 mV input FS → ±1.2 V:

`G = 1.2 V / 0.15 V ≈ 8` (±100 mV → 12; ±200 mV → 6).

**Recommended fixed gain G ≈ 8** (vs the original's 50×). It's lower purely because our ADC
has a modest input window *and* 24-bit depth — we don't need big analog gain to preserve
resolution. At G=8 the ADC noise referred to input is **0.31 µV** — 144× below the resistor
floor — so the ADC contributes nothing, and there's no case for the pricier AD7768-8.
The differential signal on the cable is ±1.2 V — plenty robust with differential drive.

## 5. Why 24-bit (since the resistor dominates)?

Not for the noise floor — even 16-bit gives a 4.6 µV input-referred LSB at G=8, already
below the 30 µV resistor floor. 24-bit is for **dynamic range / headroom**: capture the full
±150 mV signal plus residual servo offset with quantization utterly negligible, at a single
fixed gain, with no gain knob. Cheap insurance; keep it (D10).

## 6. Sampling & decimation scheme

- Run the ADS131M08 modulator fast; **output ≥1 kHz/channel** (D12). Offer selectable rates
  (e.g. 1, 2, 4 kHz) and optionally a high-rate raw stream.
- The Σ-Δ decimation filter provides anti-aliasing, so **no separate analog AA filter** is
  needed (a nice simplification) — the ~250 Hz front-end roll-off is extra margin.
- Oversample+decimate to the output rate to suppress wideband/quantization noise.

## 7. Conclusions → component commitments

1. **Fixed gain G ≈ 8** (confirm against final max-feature spec; ±150 mV input FS).
2. **ADS131M08 confirmed**; AD7768-8 not warranted (resistor floor masks the difference).
3. **Keep 24-bit** for dynamic range / no-gain-knob operation.
4. **Front-end bandwidth ~150–300 Hz** at 1 GΩ is the realistic target; **C_in ≈ 1 pF is the
   make-or-break layout spec** → drives guard-ring design (ADA4530-1 guard buffer), short
   input traces, relay placement, conformal coat.
5. **1 kHz+ sampling confirmed and beneficial**, understood as time-resolution/edge/anti-alias
   gains over a ~200–300 Hz band, not 500 Hz of bandwidth.
6. Leave a **populate-later footprint for capacitance neutralization** if higher analog
   bandwidth is ever required.

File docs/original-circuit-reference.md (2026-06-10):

# Original Giga-8dd — circuit & spec reference

Facts extracted from the vendor manuals in `../../Giga_rig_manuals/`
(`Measuring principles.pdf`, `Manual-Giga-8dd 20.pdf`). This is the system we are
modernizing.

## Primary measurement principle

An insect with piercing mouthparts and a plant are placed in series in an electrical
circuit. The insect connects via a thin gold wire to the measuring point (M); the
plant/soil connects to the supplied voltage. The recorded signal **Vi** is the voltage
across the amplifier input resistor **Ri**.

Ohm's-law relations:
- `I = Vbe/Rbe = Vi/Ri`
- emf-component sensitivity: `Vi/V = Ri / (Ri + Rbe)`
- circuit voltage: `V = Vsbe + Vs = Vbe + Vi`

Signal has two component types:
- **emf-components** — streaming potentials in stylet canals + punctured-cell membrane
  potentials (biological voltage sources).
- **R-components** — modulation of those voltages by fluctuating insect resistance
  Rbe (valve movements, etc.).

## Front-end circuit (differential probe, Fig 13B)

Classic **3-op-amp instrumentation amplifier**:
- **Amp 1** buffer: + input = insect (gold wire), high-impedance node.
- **Amp 2** buffer: + input = supplied-voltage (Vs) side of Ri, high-impedance node.
- **Ri** sits **between the two buffer + inputs**. The tiny insect–plant current flows
  through Ri; both buffers read across it. (Both buffers must therefore be electrometer
  grade — see below.)
- **Amp 3** difference amp: 1 kΩ / 50 kΩ resistors set **50× primary gain**.
- Control box adds a 2nd stage up to 2× → 50–100× total.

### Input resistance Ri — 1 GΩ / 10 TΩ switch
- **1 GΩ (default, "R+emf" mode):** records entangled R- and emf-components. The routine
  mode for all insects incl. aphids.
- **10 TΩ ("pure emf" mode):** the 10 TΩ is **not a discrete resistor** — it is the
  op-amp's own intrinsic input resistance, exposed by switching the external 1 GΩ out.
  Specialized for plant electrophysiology (membrane potentials). Suppresses R-components,
  so NOT what aphid feeding-behavior work wants.

### Critical component
- **Electrometer op-amp, input bias current < 30 fA.** With Ri = 1 GΩ, 30 fA → ~30 µV
  error. A normal op-amp (nA bias) would error by volts and not work. Original part:
  CA3240; modern candidates: ADA4530-1, LMP7721, LMC6001. Needs PCB guard rings +
  cleanliness. The same op-amp's >10^13 Ω input R provides the 10 TΩ mode for free.

## Documented specifications

| Parameter | Value |
|---|---|
| Channels | 8 |
| Primary gain (probe) | 50× |
| Total gain | 50–100× (2nd stage up to 2×) |
| Input resistance | 1 GΩ default, 10 TΩ (emf-mode) |
| Input bias current | < 30 fA |
| Supplied voltage Vs | ± 0.5 V (user-set, per channel) |
| Calibration pulse | −50 mV (added on top of Vs) |
| ADC | 14-bit, 100 Hz default sample rate |
| Output range | ± 5.85 V |
| Power | 5 V from USB → converted to bipolar ± rails |
| Probe cable | ~75 cm, shielded; BNC at probe input |

## Drift & adjustment behavior (relevant to goal #4)

- The drift that requires manual re-centering is **electrode potential** drift (galvanic
  metal–electrolyte junctions at insect and soil electrodes), ±100–200 mV, slow. The
  manuals explicitly state **op-amp drift is negligible** by comparison.
- Vs is used to compensate it AND to set the V-level, which changes the R/emf balance and
  how waveforms appear (Figs 8–9). So any automatic correction must act slowly and be
  logged, to avoid silently altering the recorded signal's character.

## Front-end bandwidth (relevant to goal #1)

Limited by Ri × stray capacitance at the input node. At 1 GΩ with ~1–5 pF this is roughly
a few hundred Hz to ~1 kHz; at 10 TΩ it is ~1000× lower (sub-Hz). Because the buffers are
in the probe, cable capacitance is post-buffer and does not limit this. Implication:
oversampling to ~1–2 kHz at 1 GΩ is meaningful; beyond that mostly oversamples noise
unless Ri is reduced.

## Aphid waveform timing (design targets)

From `aphid waveform characteristics.pdf`: waveforms A, B, C (pathway), pd (potential
drops, intracellular punctures, fast edges), E1/E2 (phloem), G (xylem), F (derailed
stylet). Listed repetition rates span ~0.2 to ~19 Hz; the fastest features of interest
are the **edges** of potential drops and the calibration pulse.

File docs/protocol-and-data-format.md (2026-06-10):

# Device↔host protocol & open data file format (draft v0.1)

Defines (A) the USB link between the device (RP2040) and host (Python app), and (B) the
on-disk recording format. Design goals: cross-platform, no custom drivers, robust to byte
loss, and **fully reconstructable** — every state change (Vs, Ri, cal pulse, servo) is
timestamped to an exact sample so the original signal can always be recovered in analysis.

---

# A. Device↔host protocol

## A.1 Transport & framing
- **USB CDC (virtual serial)** — enumerates as COM/tty, no driver install. Baud is ignored
  (USB full/high speed); throughput is ample (8 ch × 4 kHz × 3 B ≈ 96 kB/s ≪ USB CDC limit).
- **Endianness:** little-endian throughout (host + RP2040 are LE).
- **Framing:** **COBS** (Consistent Overhead Byte Stuffing) with a `0x00` frame delimiter,
  so a dropped byte costs at most one frame and the stream resyncs on the next delimiter.
- **Pre-COBS frame:** `type(1) | flags(1) | payload(N) | crc16(2)` where CRC is
  CRC-16/CCITT over `type|flags|payload`. Receivers drop frames with bad CRC.

## A.2 Message catalog

### Device → Host
| Type | Name | Payload |
|---|---|---|
| 0x01 | INFO | capabilities/identity (A.4) |
| 0x02 | SAMPLES | sample block (A.3) |
| 0x03 | EVENT | timestamped event (A.5) |
| 0x04 | ACK | `cmd_type:u8, seq:u8` (command accepted) |
| 0x05 | NACK | `cmd_type:u8, seq:u8, err:u8` |
| 0x06 | STATUS | periodic heartbeat: snapshot of per-channel Vs/Ri/servo + flags |

### Host → Device
| Type | Name | Payload |
|---|---|---|
| 0x80 | GET_INFO | — |
| 0x81 | CONFIGURE | `rate_code:u8, channel_mask:u8` (only when stopped) |
| 0x82 | START | — (begins SAMPLES + EVENT streaming) |
| 0x83 | STOP | — |
| 0x84 | SET_VS | `ch:u8, dac_code:u16` |
| 0x85 | SET_RI | `ch:u8, mode:u8 (0=1GΩ,1=10TΩ)` |
| 0x86 | CAL_PULSE | `ch:u8, action:u8 (0=off,1=on), dur_ms:u16 (0=manual)` |
| 0x87 | SERVO | `ch:u8, mode:u8 (0=off,1=acquire,2=track), target_code:u16, deadband_code:u16, flags:u8 (bit0=freeze)` |
| 0x88 | PING | — (keepalive; device replies STATUS) |

**Principle:** any host command that changes channel state is **ACKed and then echoed as an
EVENT** stamped with the sample_index at which it took effect. So the EVENT log is the single
source of truth, regardless of whether a change was host- or servo-initiated.

## A.3 Sample block (0x02)
```
block_seq         : u32
first_sample_index: u64   # monotonic counter since START; master timeline
rate_code         : u8
channel_mask      : u8    # which of 8 channels are present
n_samples         : u16   # rows in this block
status            : u8    # bit0 = any channel clipped in this block
data              : n_samples × popcount(channel_mask) × int24_le (signed)
```
- `int24_le` = 3-byte signed little-endian (the native ADS131M08 word). Channels appear in
  ascending index order per row. Blocks sized to balance latency vs overhead (e.g. 10–50 ms).

## A.4 INFO (0x01)
`format_proto_version, fw_version(maj,min,patch), n_channels, supported_rate_codes[],
adc_bits=24, adc_vref_mv, fixed_gain_x100, vs_dac_bits, vs_range_mv, serial[12]`.
The host uses this to self-configure and to write file calibration (no hard-coded constants).

## A.5 EVENT (0x03)
```
event_type : u8
channel    : u8   # 0xFF = device-wide
sample_index: u64 # exact sample at which it occurred
a, b       : i32  # type-specific
text_len   : u8 ; text[text_len]  # optional (e.g. comments)
```
| event_type | meaning | a / b |
|---|---|---|
| 1 VS_CHANGE | Vs stepped | a=old_dac, b=new_dac (text=reason: acquire/track/manual) |
| 2 RI_CHANGE | Ri mode switched | a=mode |
| 3 CAL_PULSE | calibration pulse | a=action(0/1), b=amplitude_µV (≈ −50000) |
| 4 CLIP | over-range onset/offset | a=onset(1)/offset(0) |
| 5 SERVO_STATE | servo mode change | a=mode, b=flags |
| 6 COMMENT | host/operator marker | text |
| 7 MODE_MARK | e.g. the manual's "3 pulses = normal, 5 = emf" convention | a=count |
| 8 ERROR | device error | a=code |

## A.6 Session lifecycle
1. Host opens port → `GET_INFO` → device `INFO`.
2. Host `CONFIGURE` (rate, channel mask); initial per-channel `SET_VS`/`SET_RI`/`SERVO`.
3. Host `START` → device streams `SAMPLES` + `EVENT`; periodic `STATUS`.
4. Live control via `SET_*`/`CAL_PULSE`/`SERVO`; each → `ACK` + an `EVENT`.
5. Host `STOP` → device halts, final `ACK`.

Clock: `sample_index` is the master timeline. Absolute time of sample *i* =
`start_time_utc + i / sample_rate`. All events reference `sample_index`, so nothing depends
on host-side timing jitter.

---

# B. Data file format

## B.1 Container: HDF5
**HDF5** is the canonical recording format — self-describing, handles hour-long multichannel
time series with chunking + compression, and is first-class in Python (`h5py`), MATLAB, R,
Julia. Written **incrementally** (resizable datasets + periodic flush) so a crash leaves a
valid file up to the last flush.

## B.2 Schema
```
/                       (root attributes)
   format_version, device_serial, firmware_version,
   start_time_utc (ISO-8601), sample_rate_hz, n_channels, channel_mask,
   adc_bits=24, adc_vref_v, fixed_gain, vs_range_mv, vs_dac_bits,
   operator, experiment_id, notes

/samples                int32 [n_samples, n_active_channels]   (24-bit codes)
   chunked (e.g. 1 s × channels), gzip or lzf compressed
   attrs: channel_ids[], code_to_volts_adc (LSB→V at ADC),
          adc_to_input_referred (÷ fixed_gain)   # code → input-referred volts

/events                 compound table (one row per event)
   sample_index:u64, time_s:f64, type:enum/str, channel:i8,
   a:i32, b:i32, text:vlen-str
   # VS_CHANGE, RI_CHANGE, CAL_PULSE, CLIP, SERVO_STATE, COMMENT, MODE_MARK, ERROR

/channels/<id>          (optional per-channel metadata group)
   attrs: insect_id, species, plant, electrode notes, initial Vs/Ri, ...
```
Optionally store a convenience `/vs_applied` decimated trace, but it is always derivable from
`/events`.

## B.3 Reconstruction conventions (the point of all this)
- **Code → input-referred volts:** `V_in = code × (adc_vref / 2^23) / fixed_gain`.
- **Applied Vs at sample *i*:** `Vs0 + Σ(VS_CHANGE steps with sample_index ≤ i)`.
  - *As-recorded* (servo-corrected) trace = `/samples` directly.
  - *Uncompensated* trace = add the applied-Vs offset back (input-referred). Because the
    keep-in-range servo (D11) only steps Vs occasionally and every step is logged, the true
    continuous signal is always recoverable.
  - *Display* detrend (software high-pass, D11) is a view only — never written into `/samples`.
- **Calibration pulse:** during a CAL_PULSE on→off interval a known ≈ −50 mV is injected at
  the input; the step response gives the scale check and the insect-resistance estimate (per
  the manual's method). Cal intervals are in `/events`.

## B.4 Crash-safety & live capture
Write `/samples` and `/events` incrementally with periodic `flush()` (e.g. every 1–2 s). A
power loss leaves a valid HDF5 readable up to the last flush. (Optional: also keep a raw
append-only frame log alongside as a belt-and-suspenders capture that can be re-finalized.)

## B.5 Versioning & export
- `format_version` (file) and `format_proto_version` (link, in INFO) are independent and
  checked on open.
- **Exports:** CSV (samples + events) for spreadsheets; **NWB** (Neurodata Without Borders,
  HDF5-based) as a future archival/sharing target to align with the electrophysiology
  ecosystem.

---

## Open items
- Exact rate_code table, block size, STATUS cadence, NACK error codes.
- Whether to compress `/samples` with gzip (smaller) vs lzf (faster) by default.
- Confirm ADS131M08 code scaling (FS, ref) against datasheet at implementation.
- Python reference implementation of the framing + reader (lands in `software/`).

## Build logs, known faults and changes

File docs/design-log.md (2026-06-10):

# Design log — locked decisions & rationale

Decision records for the EPG redesign, newest at the bottom. Each entry: the decision,
why, and any constraints it imposes. Open questions tracked at the end.

---

## D1 — Keep the differential 3-op-amp instrumentation-amp front end
**Decision:** Reuse the proven differential in-amp topology (2 electrometer buffers +
difference amp, 50× primary gain) rather than inventing a new front end.
**Why:** It is a textbook, well-characterized circuit; the original's choice is sound.
The hard part is the electrometer op-amp + Gigaohm node, which we keep.

## D2 — Keep the 1 GΩ / 10 TΩ ("emf-mode") switch
**Decision:** Default 1 GΩ (entangled R+emf, the routine aphid mode); retain a switch to
10 TΩ pure-emf mode.
**Why:** The 10 TΩ value is the op-amp's own input resistance once the external 1 GΩ is
switched out — so the feature costs only a **low-leakage switch** (reed relay or guarded
analog switch), given we already use an electrometer op-amp. Near-zero cost, preserves
plant-electrophysiology capability, loses nothing for routine work.
**Constraint:** switch must be genuinely low-leakage (pA); immaculate board cleanliness /
conformal coat around the input node.

## D3 — Per-channel daughtercard architecture; design for 8, build 1 first
**Decision:** Implement the analog front end as a small per-channel daughtercard (carrying
the high-impedance node: in-amp + Ri + low-leakage switch) that connects to a shared
motherboard. Only **low-impedance buffered analog** crosses the connector.
**Why:** Engineering effort (electrometer layout, firmware, software, Vs servo) is nearly
independent of channel count — only the analog front-end BOM scales (~$30/ch vs ~$30–40
fixed shared). Prototype/validate one channel end-to-end, then populate the rest with zero
redesign. Matches the original's individually-replaceable-probe philosophy.
**Rough BOM:** 1-channel ≈ $60, 8-channel ≈ $270 (single-unit, excl. enclosure/assembly).

## D4 — Automatic drift correction = slow hardware Vs servo + logging
**Decision:** Put Vs under DAC control and run a slow firmware servo that corrects only
minutes-scale baseline drift toward a **user-set target level**, and **logs every Vs
change** into the recording.
**Why:** The drift is electrode-potential drift (not op-amp drift). Vs also sets the R/emf
balance and waveform appearance, so correction must be slow and fully reconstructable in
analysis — never a silent fast auto-center.

## D5 — Software: Python + pyqtgraph/Qt; device = USB CDC
**Decision:** Cross-platform acquisition + analysis app in Python (pyqtgraph/Qt). Device
enumerates as a standard **USB CDC serial** device (no custom drivers).
**Why:** Strong scientific ecosystem, fast real-time plotting, runs on any OS. USB CDC
removes the Windows-only driver problem of the original Stylet+.

## D6 — Central digitization with differential cable drive
**Decision:** Digitize **centrally** on the motherboard with one shared
**simultaneous-sampling Σ-Δ ADC** (e.g. ADS131M08 class). Each daughtercard sends its
buffered signal **differentially** over the cable (add one inverting op-amp on the card to
make the complementary line); the ADC's native **differential input** does the A−B
subtraction.
**Why:** Keeps all switching/clocks far from the femtoamp 1 GΩ node (the original
deliberately keeps digital out of the cage). One shared ADC gives free inter-channel
sample synchronization, lower parts count, simpler firmware. Differential drive adds
common-mode rejection of 50/60 Hz cable pickup and breaks ground loops — most of the noise
benefit of per-probe digitizing, without the noise penalty.
**Constraint:** differential swing must stay within ADC input range / card rails; signal
pair should be twisted/paired for good CMRR. Revisit per-probe digital only if long-cable
field use becomes a primary requirement.
**Bonus simplification:** the −50 mV calibration pulse becomes a firmware-commanded step
on the Vs line — no dedicated cal hardware or conductor.

## D7 — Independent probe heads on multi-conductor cables; Lemo/ODU + BNC
**Decision:** Each daughtercard lives in its own probe head on a **flexible
~8-conductor shielded cable** to the motherboard (probes are positioned individually on
stands inside the cage — no backplane). Per-channel cable carries: differential signal
pair A/B (twisted), Vs (with cal pulse riding on it), +V, −V, analog ground, Ri-switch
control, + overall shield ≈ **7 conductors + shield**. Connectors: **BNC** at the probe
tip for the insect electrode; **Lemo/ODU push-pull 8-pin** probe-to-motherboard
(locking, best shielding/durability). Cost-softeners: PCB-mount sockets on the
motherboard side; ODU/Fischer/compatible series can undercut genuine Lemo.
**Why:** Matches how EPG probes are actually used (individually clamped near each insect).
David chose the premium connector for shield quality, locking security, and longevity.
**Bonus:** cal pulse rides on the Vs line (no dedicated conductor); ±V rails sent from the
motherboard so nothing switches near the femtoamp node.

## D8 — Electrometer input op-amp: ADA4530-1; Ri switch: latching reed relay
**Decision:** Input buffers = **ADA4530-1** (Analog Devices femtoampere electrometer amp),
two per channel (both sit across Ri, so both must be electrometer grade). The downstream
difference amp and the differential-drive inverter are ordinary precision op-amps. Ri
(1 GΩ/10 TΩ) switch = **latching reed relay** (>10^14 Ω open isolation; energized only
during the rare mode change → no continuous coil current/field near the node).
**Why:** ADA4530-1's 20 fA max bias and **integrated guard buffer** make the hardest part
of the build (femtoamp board leakage / guard ring) near-turnkey, and it's ideal for the
10 TΩ mode. ~$10–12 ea (~$170 across 8 ch) — small premium to de-risk the make-or-break
subsystem; consistent with the premium/longevity choices already made. A semiconductor
analog switch's pA leakage would compromise the 10 TΩ mode, hence the reed relay.
**Constraint:** PCB guard ring driven by the ADA4530-1 guard pin; conformal coat / clean
input node.

## PRIORITY NOTE (David, 2026-06-10)
Not very cost-sensitive. **Maximize sensitivity / signal quality and operational
simplicity at every step**; cost is secondary. Default to the higher-sensitivity,
lower-noise, more-foolproof option; automate rather than add knobs. (Mirrors memory
`epg-priorities`.)

## D9 — Fixed gain (no programmable-gain stage); sensitivity from oversampling
**Decision:** Single **fixed** primary gain in the probe (≥50×, exact value set by a noise
budget so the front end, not the ADC, is the limiting noise source). No variable/2nd-stage
gain. Rely on the 24-bit ADC's dynamic range + **oversampling & decimation** for effective
resolution and SNR.
**Why:** Best on both of David's axes — operational simplicity (the only per-channel
adjustment left is Vs, which is auto-servoed per D4) and sensitivity (a PGA would add noise
/ switching artifacts; oversampling improves SNR for free and also feeds goal #1). Digital
zoom in software replaces the old manual gain knob.

## D10 — Core motherboard ICs
**Decision:**
- **ADC:** ADS131M08 — 8-ch, 24-bit, simultaneous-sampling Σ-Δ, native differential inputs
  (serves as the differential-cable receiver), SPI, up to 32 kSPS/ch. Baseline; **AD7768-8**
  kept as a higher-performance upgrade path if the noise budget calls for it.
- **Vs DAC:** DAC8568 — 8-ch, 16-bit, internal ref, SPI (~15 µV steps over ±0.5 V).
- **MCU:** **RP2040** (David's choice) — ample for the data rate, USB, great tooling; all
  digital stays on the motherboard.
- **Bipolar power:** LM27762 — clean ±rails from USB 5 V with integrated low-noise LDOs;
  digital 3.3 V from a separate LDO. Stays within USB current budget.

## D11 — Vs auto-servo: two-phase, keep-in-range, software-centered display
**Decision:** Firmware Vs servo with two phases.
- **Acquire** (recording start / on demand): quickly seek Vs to bring each channel's
  baseline to target — automates the start-of-recording adjustment the manual calls
  essential.
- **Track** (during recording): **keep-in-range only** — hardware moves Vs *only* when
  drift threatens to clip the ADC (mirrors the manual's "only re-adjust if off scale").
  Slow loop (τ ~ tens of s, well below waveform content); pauses during the cal pulse;
  per-channel **freeze** + **manual override** always available.
**Logging:** every Vs change recorded (timestamp, old→new) as a side channel so analysis
can add the steps back and recover the true uncorrected trace.
**Display:** centered in **software** (high-pass/detrend), independent of the hardware — so
"looks centered" is decoupled from "Vs moved." Minimizes interference with the R/emf
balance; hardware interventions are rare, discrete, logged events.
**Why:** Best for David's sensitivity + simplicity priorities and scientifically faithful
(doesn't silently eat slow biological level changes like sustained E2). The electrode-drift
correction is still needed because the fixed 50× amplifies DC drift into volts that would
otherwise rail the ADC.

## D12 — Sample rate: runtime-configurable, default 1 kHz (for exploration, not a fixed spec)
**Decision:** Sample rate is a **runtime recording parameter** (e.g. 250 / 500 / 1000 /
2000 / 4000 Hz), default **1000 Hz** (vs the original's 100 Hz). Not a fixed hardware target.
Oversample + decimate for SNR; optionally store a high-rate raw stream.
**Rationale / correction (David, 2026-06-10):** Aphid signal bandwidth is genuinely
*unknown* — prior data sampled at 100 Hz only resolves <50 Hz, so the field has never been
able to look higher; the original instrument may have been self-limiting. Worth exploring,
but we don't know that we need 1 kHz. **Key finding: sample rate is NOT a hardware design
driver** — 500 vs 1000 vs 2000 Hz changes nothing in the ADC chip, front end, MCU, USB,
power, layout, firmware, or software (only the Nyquist ceiling and file size). So we make it
configurable, default high, and let real recordings reveal whether faster aphid content
exists. The genuinely separate lever is *analog bandwidth* (see below), which is independent
of sample rate.
**Analog-bandwidth note:** the ~150–300 Hz front-end ceiling (Ri·C_in, see D13) is what
actually limits resolvable content; pushing past it needs **capacitance neutralization**, for
which a populate-later footprint is reserved. Trigger to populate it = finding real energy
near the roll-off during high-rate exploratory recordings. C_in ≈ 1 pF layout discipline
(guard ring + ADA4530-1 guard buffer) remains the make-or-break spec regardless.

## D13 — Noise & bandwidth budget results (see noise-bandwidth-budget.md)
**Findings:**
- **Noise floor is the 1 GΩ resistor's thermal noise (~30–65 µV RMS in-band)** — op-amp and
  ADC noise are 100×+ below it. Fundamental to the 1 GΩ choice; the original lives here too.
- **Fixed gain G ≈ 8** (not 50×) — maps ±150 mV input FS to the ADS131M08 ±1.2 V range; the
  24-bit depth (not analog gain) preserves resolution. Confirm vs final max-feature spec.
- **ADS131M08 confirmed; AD7768-8 not warranted** (resistor floor masks any ADC-noise gain).
- **Keep 24-bit** for dynamic range / no-gain-knob operation (not for the floor).
- **Realistic front-end bandwidth at 1 GΩ ≈ 150–300 Hz** (probing), set by Ri·C_in. Hitting
  500 Hz needs C_in < ~0.6 pF (impractical). So **C_in ≈ 1 pF is the make-or-break layout
  spec** (guard ring + short traces). 1 kHz sampling is confirmed/beneficial but understood
  as time-resolution/edge/anti-alias gains over a ~200–300 Hz band, *not* 500 Hz of
  bandwidth. Leave a populate-later footprint for **capacitance neutralization** if more
  analog BW is ever needed.
- Σ-Δ decimation filter handles anti-aliasing → **no separate analog AA filter**.

## D14 — Device↔host protocol + open data format (see protocol-and-data-format.md)
**Decision (draft v0.1):**
- **Link:** USB CDC (no drivers), little-endian, **COBS** framing + CRC-16/CCITT, typed
  messages. Device→host: INFO/SAMPLES/EVENT/ACK/NACK/STATUS. Host→device:
  GET_INFO/CONFIGURE/START/STOP/SET_VS/SET_RI/CAL_PULSE/SERVO/PING.
- **Master timeline = `sample_index`** (monotonic from START); absolute time =
  start_time_utc + index/rate. Every state change (Vs, Ri, cal, servo) — host- *or*
  servo-initiated — is emitted as a `sample_index`-stamped **EVENT**, making the event log
  the authoritative, reconstructable record. Device streams **raw 24-bit ADC codes**
  (lossless); calibration lives in metadata.
- **File:** **HDF5** canonical (`/samples` int32 codes chunked+compressed, `/events`
  compound table, root + per-channel metadata), written incrementally with periodic flush
  for crash-safety. Reconstruction conventions defined (code→input-referred volts; applied-Vs
  = Vs0 + Σ logged steps; display detrend is view-only, never written). CSV + future **NWB**
  export.
**Why:** Cross-platform + driver-free (goal #5); full reconstructability protects the science
given the Vs servo (D11); HDF5 is the scientific-time-series standard. **Unblocks the Python
software** to proceed against this contract in parallel with hardware.

## D15 — Python software v0.1 built & tested against a mock device (`software/`)
**Done:** Implemented the host software package `epgrig` and verified the *entire* pipeline
in software, no hardware:
- `protocol.py` — COBS+CRC framing + message codecs (pure stdlib).
- `mock_device.py` — synthetic aphid-like waveforms + electrode drift + keep-in-range Vs
  servo, emitting real protocol frames.
- `acquisition.py` / `recorder.py` / `reader.py` — parse → incremental HDF5 → reconstruct
  (input-referred volts + applied-Vs from the event log).
- `dsp.py` — display detrend (moving-average + streaming one-pole HP), view-only.
- `gui.py` + `scripts/run_gui.py` — live pyqtgraph display (optional Qt).
- `scripts/record_mock.py` — headless end-to-end demo.
**Verified:** 15 tests pass (protocol round-trips incl. COBS/CRC + parser resync; pipeline
mock→HDF5→reconstruct; dsp). Demo: 30 s × 8 ch @ 1 kHz → 843 KB HDF5, 0 CRC errors, servo
fired (VS_CHANGE events logged), input-referred trace bounded while uncompensated shows the
removed drift — i.e. D11/D14 behavior proven. Real hardware later drops in behind the same
protocol (swap mock byte-stream for a pyserial USB-CDC port).
**Env note:** dev verified with system Python 3.9 + user-installed numpy/h5py; Qt not present
here so the GUI is written + parse-checked but not launched.

### D15 follow-ups (GUI + mock command path)
- GUI gained a **sample-rate selector** (from `Info.supported_rates`; reconfigures live,
  locked during recording), **Record/Stop** + file/metadata, **markers**, working **detrend**
  checkbox, and **per-channel controls** (Vs / servo off-acquire-track / Ri 1G-10T / cal pulse).
- Mock device now **acts on** SET_VS/SET_RI/SERVO/CAL_PULSE and emits the matching logged
  events (cal injects −50 mV + auto-offs; servo respects mode). `tests/test_commands.py` added
  → **19 tests pass**.
- **Repo:** local git initialized at `EPG_redesign/` (vendor PDFs/installers excluded),
  initial commit made. GitHub remote `DavidSternLab/ElectricalPenetrationGraph` pending
  David's auth (no gh/token/SSH in the dev environment).

## D16 — Single-channel schematic v0.1 + SPICE verification (`hardware/`)
**Done:** First schematic-level design (`hardware/single-channel-schematic.md`): block diagram,
signal chain, component table, power tree, layout-critical notes. Topology decided:
- Daughtercard: **A1, A2 = ADA4530-1** unity-gain electrometer followers sensing the two ends
  of Ri; **Ri = 1 GΩ + latching reed relay** (open → 10 TΩ intrinsic); Vs_in applied at the S
  node (cal pulse rides on it); **FDA = ADA4940-1** provides the gain *and* the differential
  cable drive in one stage. **Gain G ≈ 8** via Rg=1.0k / Rf=8.06k (D13).
- Motherboard: ADS131M08 diff input (Σ-Δ AA → no analog AA filter), DAC8568→scale/offset
  (±0.5 V)→~10 Hz LP→Vs_in, RP2040, LM27762 ±5 V + 3.3 V LDO, on-card latching-relay driver.
**Verified by SPICE** (`hardware/sim/single_channel.cir`, ngspice): Ohm's-law divider
Vi = 0.500 mV ✓, differential gain Vout = 4.00 mV (=8×) ✓, and **front-end f₋₃dB = 318.3 Hz,
matching the analytic `1/(2π·(Rbe‖Ri)·Cin)` to 100%** — empirically confirming the D13
bandwidth budget and that **Cin ≤ ~1 pF is the dominant layout lever**.

## D17 — RP2040 firmware skeleton + portable C protocol (`firmware/`)
**Done:**
- `firmware/proto/epg_proto.{h,c}` — the protocol codec in **portable C** (COBS, CRC-16,
  i24, frame builders, incremental parser, command decoders), mirroring the Python codec.
- `firmware/test/` — host-compiled **C selftest** (`make check`) and a **cross-language
  interop test** (`make interop`, `interop_test.py`) that builds frames in C and parses them
  in Python and vice-versa. **Proven byte-for-byte compatible both directions** → the
  firmware will talk to the existing host GUI unchanged.
- `firmware/src/` — RP2040 Arduino app skeleton: `main.cpp` (USB-CDC loop, command dispatch,
  DRDY-driven 8-ch acquisition, block streaming, keep-in-range Vs servo, sample-stamped
  EVENTs), `ads131m08.{h,cpp}`, `dac8568.{h,cpp}`, `board.h` pin map; `platformio.ini`
  (arduino-pico) compiling the shared proto/ alongside src/.
**Verified:** C selftest (7 checks) + interop (both directions) pass; all 4 Python host test
files still pass. **Not hardware-tested:** ADC/DAC register sequences + relay/servo scaling
are marked `TODO: verify vs datasheet`; src/ not compiled here (needs RP2040 toolchain).

## D18 — Netlist + KiCad schematic capture (ERC-clean, `hardware/netlist/`)
**Done:**
- `channel_netlist.py` — the single-channel daughtercard as machine-checkable data
  (23 components, 71 pins, 21 nets) + an **ERC-style checker**: 0 errors / 0 warnings
  (every pin connected exactly once; power + diff pair consistent). Generates
  `connection-table.md`.
- `gen_kicad_sch.py` — emits a real **`single_channel.kicad_sch`** from that netlist (box
  symbols + global-label-per-pin connectivity). Validated with **`kicad-cli` (KiCad 10.0.3):
  upgrade + ERC pass with only benign warnings** — 23 "symbol library 'epg' not configured"
  (symbols are embedded/self-contained) and 3 isolated-label (the intentional single-node
  nets SHLD/GUARD1/GUARD2). **Zero connectivity errors.** Rendered to `single_channel.svg` /
  `.pdf` and eyeballed — all parts, pins, and net labels present and correct.
**Note:** box symbols (not op-amp glyphs) and no footprints yet — intended as a verified
first capture; swap to library symbols + assign footprints during manual cleanup in KiCad
(now installed). The netlist data is the source of truth and regenerates the sheet.

## D19 — PCB layout groundwork + hand-off package (`hardware/pcb/`, `pcb-layout.md`)
**Context:** David will recruit a KiCad layout engineer to finish; this is the verifiable
groundwork + hand-off (routing of an fA front end is deliberately a human task).
**Done:**
- **Footprints assigned** to all 23 parts in `channel_netlist.py` (verified present in KiCad
  10 libs; 3 PLACEHOLDERs flagged: Lemo/ODU J2, latching reed relay K1, ADA4940 LFCSP).
  Schematic now carries a `Footprint` property per symbol (so *Update PCB from Schematic*
  pulls nets+footprints). Connection table regenerated with a footprint column.
- **Starting board** `pcb/single_channel.kicad_pcb` generated via the `pcbnew` API
  (`gen_pcb_placement.py`): 23 footprints pre-placed with electrometer-aware intent (BNC/A1
  input cluster left → FDA centre → Lemo output right), 60×40 mm outline, 4 layers.
  Validated with `kicad-cli pcb drc`: **0 unconnected/structural errors**; 40 items are
  placement-refinement only (courtyard/silk/edge/clearance) for the layout engineer.
  Rendered `pcb/board_top.svg` and eyeballed.
- **`hardware/pcb-layout.md`** — the layout spec / hand-off: 4-layer stackup; the make-or-break
  input-node rules (Cin≤1 pF, no plane under M, no vias on M, **driven guard rings** from the
  ADA4530-1 GUARD pins, surface-leakage slot + conformal coat + cleanliness); net classes
  (HighZ/Guard/Power/Signal/Diff); placement intent; grounding/shielding.
- **`pcb/single_channel.kicad_dru`** — custom design rules (HighZ clearance/no-via/thin-track,
  diff-pair skew, fab floors). Confirmed it **parses cleanly** (kicad-cli DRC, 0 rule errors).

---

## Open questions / next pivots
- **Layout engineer:** Update-PCB-from-Schematic, refine placement (clear the 40 items),
  implement the guard scheme, route, swap the 3 PLACEHOLDER footprints, DRC-clean.
- Finalize FDA supply/VOCM, relay-driver sub-circuit, ADC RC + CLKIN, Vs scale/offset, USB budget.
- Firmware hardware bring-up: ADS131M08/DAC8568 register init + CRC, Vs calibration, relay
  pulse driver; compile with PlatformIO + flash + talk to the host GUI over a real port.
- Mechanical: shielded probe-head enclosure, guard-ring layout, conformal coating.
- Software niceties: analysis/Y-zoom UI, waveform labeling, NWB export, real serial transport.
- Channel count confirm (assume 8).
- USB bipolar-rail generation.
- Vs servo loop details (rate, target, logging format).
- Open data file format definition + converter.

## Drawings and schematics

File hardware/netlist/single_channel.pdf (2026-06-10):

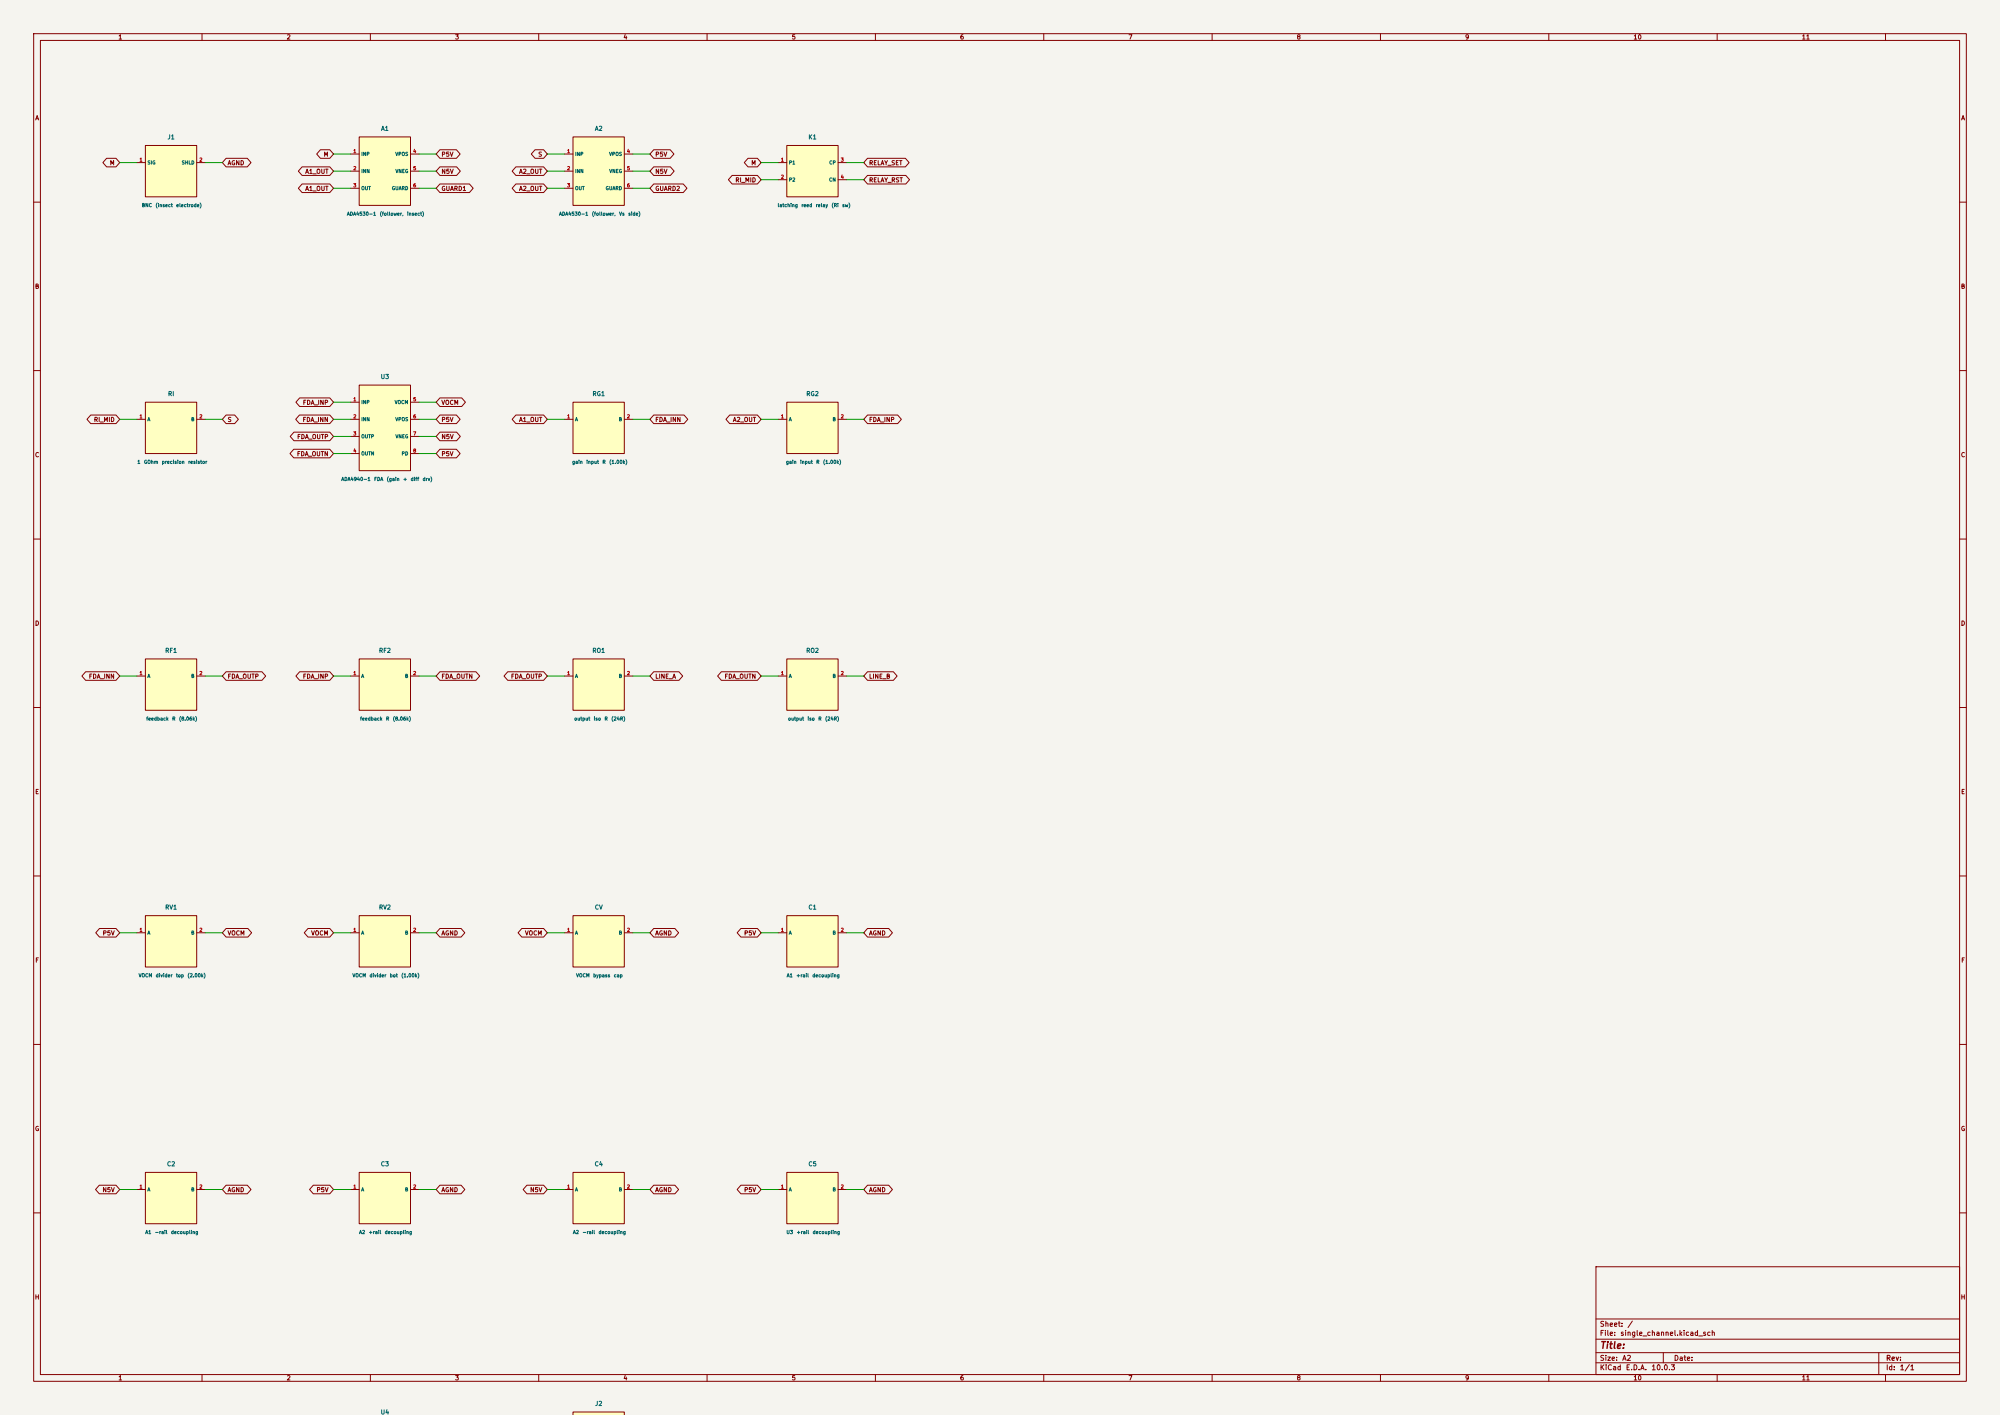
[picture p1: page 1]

2 RI 1 GOhm precision resistor

ADA4940-1 FDA (gain + diff drv)

Size: A2 | Rev:
KiCad E.D.A. 10.0.3 | Id: 1/1

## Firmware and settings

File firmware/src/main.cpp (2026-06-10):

/* EPG rig — RP2040 firmware (Arduino-pico).  SKELETON / not yet hardware-tested.
 *
 * Implements the device side of the protocol in ../proto/epg_proto.{h,c} (the SAME codec
 * the host GUI uses — verified byte-for-byte by firmware/test/interop_test.py), so this
 * talks directly to software/epgrig over USB CDC.
 *
 * Pipeline: on ADC DRDY -> read 8 ch -> run keep-in-range Vs servo -> append to block;
 * flush a SAMPLES frame every BLOCK_MS; handle host commands; emit EVENT on every state
 * change (Vs/Ri/cal/servo) stamped with the current sample_index.
 */
#include <Arduino.h>
#include <SPI.h>
extern "C" {
#include "epg_proto.h"
}
#include "board.h"
#include "ads131m08.h"
#include "dac8568.h"

// ---- device identity / config ----
static const uint16_t RATES[] = {250, 500, 1000, 2000, 4000};
static epg_info_t INFO = { EPG_PROTO_VERSION, 0,1,0, N_CHANNELS,
                           1200, 800, 1000, 16, 24, RATES, 5, "EPG-RP2040-0001" };

static ADS131M08 adc;
static DAC8568   dac;

// runtime state
static volatile bool running = false;
static uint8_t  channel_mask = 0xFF;
static uint8_t  rate_code = 2;            // default 1000 Hz
static uint64_t sample_index = 0;
static uint32_t block_seq = 0;
static const float BLOCK_MS = 50.0f;

// per-channel state
static uint16_t vs_dac[N_CHANNELS];
static uint8_t  servo_mode[N_CHANNELS];
static uint8_t  ri_mode[N_CHANNELS];
static bool     cal_active[N_CHANNELS];
static uint32_t cal_until_ms[N_CHANNELS];
static float    baseline[N_CHANNELS];     // slow EMA of output code (servo)

// block accumulation
static int32_t  blk_samples[256][N_CHANNELS];
static uint16_t blk_n = 0;
static uint64_t blk_first = 0;
static uint8_t  blk_status = 0;
static uint32_t last_flush_ms = 0;

// ---- framing helpers ----
static void send_frame(uint8_t type, const uint8_t *payload, size_t plen) {
    uint8_t frame[600];
    size_t fl = epg_encode_frame(type, 0, payload, plen, frame);
    Serial.write(frame, fl);
}
static void emit_event(uint8_t etype, uint8_t ch, int32_t a, int32_t b,
                       const char *text) {
    uint8_t pay[64];
    uint8_t tl = 0; while (text && text[tl] && tl < 40) tl++;
    size_t pl = epg_build_event(etype, ch, sample_index, a, b, text, tl, pay);
    send_frame(T_EVENT, pay, pl);
}
static void send_ack(uint8_t cmd) { uint8_t p[2]={cmd,0}; send_frame(T_ACK, p, 2); }

// ---- helpers ----
static int active_count() { return __builtin_popcount(channel_mask); }

static void set_vs(uint8_t ch, uint16_t dac_code, const char *reason) {
    uint16_t old = vs_dac[ch];
    vs_dac[ch] = dac_code;
    dac.writeChannel(ch, dac_code);
    emit_event(EV_VS_CHANGE, ch, old, dac_code, reason);
}

static void set_ri(uint8_t ch, uint8_t mode) {
    ri_mode[ch] = mode;
    // TODO: shift-register pulse to the channel's latching reed relay (set/reset).
    emit_event(EV_RI_CHANGE, ch, mode, 0, "");
}

// keep-in-range / acquire servo, mirroring the host mock (D11)
static void servo_step(uint8_t ch, int32_t code) {
    uint8_t m = servo_mode[ch];
    if (m == SERVO_OFF) return;
    baseline[ch] = 0.999f * baseline[ch] + 0.001f * (float)code;
    const float FS = 8388607.0f;
    float thresh = (m == SERVO_ACQUIRE) ? 0.30f : 0.80f;
    if (fabsf(baseline[ch]) > thresh * FS) {
        // step Vs DAC toward recentering (sign/scale set by hardware; placeholder gain)
        int32_t step = (int32_t)(-baseline[ch] / FS * 2000.0f);  // ~codes; TODO calibrate
        int32_t nd = (int32_t)vs_dac[ch] + step;
        if (nd < 0) nd = 0; if (nd > 65535) nd = 65535;
        set_vs(ch, (uint16_t)nd, (m == SERVO_ACQUIRE) ? "acquire" : "track");
        baseline[ch] = 0.0f;
    }
}

// ---- command handling ----
static void on_frame(uint8_t type, uint8_t flags, const uint8_t *p, size_t n, void *u) {
    (void)flags; (void)u;
    switch (type) {
        case T_GET_INFO: { uint8_t pay[128]; size_t pl = epg_build_info(&INFO, pay);
                           send_frame(T_INFO, pay, pl); break; }
        case T_CONFIGURE: if (n >= 2 && !running) { rate_code = p[0]; channel_mask = p[1]; }
                          send_ack(type); break;
        case T_START: running = true; sample_index = 0; block_seq = 0; blk_n = 0;
                      blk_first = 0; last_flush_ms = millis(); send_ack(type); break;
        case T_STOP:  running = false; send_ack(type); break;
        case T_SET_VS: { epg_set_vs_t c; if (epg_parse_set_vs(p,n,&c)) set_vs(c.ch,c.dac,"manual");
                         send_ack(type); break; }
        case T_SET_RI: { epg_set_ri_t c; if (epg_parse_set_ri(p,n,&c)) set_ri(c.ch,c.mode);
                         send_ack(type); break; }
        case T_CAL_PULSE: { epg_cal_t c; if (epg_parse_cal(p,n,&c)) {
                              if (c.action == 1) { cal_active[c.ch]=true;
                                  cal_until_ms[c.ch]=millis()+(c.dur_ms?c.dur_ms:500);
                                  emit_event(EV_CAL_PULSE,c.ch,1,-50000,""); }
                              else { cal_active[c.ch]=false; emit_event(EV_CAL_PULSE,c.ch,0,-50000,""); }
                          } send_ack(type); break; }
        case T_SERVO: { epg_servo_t c; if (epg_parse_servo(p,n,&c)) {
                          servo_mode[c.ch]=c.mode; emit_event(EV_SERVO_STATE,c.ch,c.mode,0,""); }
                        send_ack(type); break; }
        case T_PING: send_ack(type); break;
        default: { uint8_t p2[3]={type,0,1}; send_frame(T_NACK,p2,3); }
    }
}

static epg_parser_t parser;

void setup() {
    Serial.begin(115200);                 // USB CDC; baud ignored
    for (int i=0;i<N_CHANNELS;i++){ vs_dac[i]=32768; servo_mode[i]=SERVO_TRACK;
                                    ri_mode[i]=RI_1G; cal_active[i]=false; baseline[i]=0; }
    pinMode(PIN_SR_DATA,OUTPUT); pinMode(PIN_SR_CLK,OUTPUT); pinMode(PIN_SR_LATCH,OUTPUT);
    dac.begin(PIN_DAC_CS, PIN_DAC_LDAC);
    adc.begin(PIN_ADC_CS, PIN_ADC_DRDY, PIN_ADC_RESET);
    epg_parser_init(&parser, on_frame, nullptr);
}

static void flush_block() {
    if (blk_n == 0) return;
    uint8_t pay[8 + 256*3*N_CHANNELS];
    size_t pl = epg_build_sampleblock_header(block_seq++, blk_first, rate_code,
                                             channel_mask, blk_n, blk_status, pay);
    for (uint16_t r=0;r<blk_n;r++)
        for (int c=0;c<N_CHANNELS;c++)
            if (channel_mask & (1<<c)) { epg_pack_i24(blk_samples[r][c], pay+pl); pl+=3; }
    send_frame(T_SAMPLES, pay, pl);
    blk_n = 0; blk_status = 0;
}

void loop() {
    // 1) drain host commands
    while (Serial.available() > 0) {
        uint8_t b = (uint8_t)Serial.read();
        epg_parser_feed(&parser, &b, 1);
    }
    if (!running) return;

    // 2) acquire on data-ready
    if (adc.dataReady()) {
        int32_t ch[8];
        if (adc.readFrame(ch)) {
            if (blk_n == 0) blk_first = sample_index;
            for (int c=0;c<N_CHANNELS;c++) {
                blk_samples[blk_n][c] = ch[c];
                servo_step((uint8_t)c, ch[c]);
                if (cal_active[c] && (int32_t)(millis()-cal_until_ms[c]) >= 0) {
                    cal_active[c]=false; emit_event(EV_CAL_PULSE,c,0,-50000,"");
                }
            }
            blk_n++;
            sample_index++;
            if (blk_n >= 256) flush_block();
        }
    }

    // 3) periodic block flush
    if ((int32_t)(millis() - last_flush_ms) >= (int32_t)BLOCK_MS) {
        flush_block();
        last_flush_ms = millis();
    }
}

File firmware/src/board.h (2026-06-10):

/* RP2040 pin map for the EPG motherboard (draft — verify against the PCB). */
#ifndef EPG_BOARD_H
#define EPG_BOARD_H

#include <Arduino.h>

// ADS131M08 (8-ch 24-bit ADC) on SPI0
static const int PIN_ADC_SCK   = 2;
static const int PIN_ADC_MOSI  = 3;
static const int PIN_ADC_MISO  = 4;
static const int PIN_ADC_CS    = 5;
static const int PIN_ADC_DRDY  = 6;   // active-low data-ready (IRQ)
static const int PIN_ADC_RESET = 7;

// DAC8568 (8-ch 16-bit, Vs per channel) — shares the SPI0 bus
static const int PIN_DAC_CS    = 8;
static const int PIN_DAC_LDAC  = 9;

// Ri (1 GΩ / 10 TΩ) latching relays driven via a 74HC595 shift-register chain
// (one bit pair per channel set/reset); keeps GPIO count low.
static const int PIN_SR_DATA   = 10;
static const int PIN_SR_CLK    = 11;
static const int PIN_SR_LATCH  = 12;

static const int N_CHANNELS    = 8;

#endif // EPG_BOARD_H

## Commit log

2026-06-10 Initial commit: EPG rig redesign — design docs + Python software (v0.1)
    Open redesign of the EPG (Electrical Penetration Graph) recording rig to
    replace the commercial Giga-8dd. Goals: better temporal resolution, lower
    cost, simpler construction, automatic voltage-drift correction, and
    cross-platform software.
    - docs/: design log (decisions D1–D15 + rationale), original-circuit
    reference, system architecture, noise+bandwidth budget, device<->host
    protocol + HDF5 data format.
    - software/epgrig: protocol (COBS+CRC framing), in-process mock device,
    acquisition, crash-safe HDF5 recorder, reader+reconstruction, display
    DSP, and a pyqtgraph acquisition GUI (record/markers/per-channel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
2026-06-10 docs: log sample-rate selector, per-channel controls, and git setup
2026-06-10 gui: add "All channels" option to channel control
    Selecting "All channels" broadcasts Vs / servo / Ri / cal-pulse commands to
    every active channel at once.
2026-06-10 hardware: single-channel schematic v0.1 + SPICE verification
    Front end: ADA4530-1 electrometer followers across Ri (1 GΩ + latching reed
    relay), ADA4940-1 FDA providing gain ~8 and the differential cable drive;
    motherboard = ADS131M08 / DAC8568 / RP2040 / LM27762. ngspice sim confirms the
    Ohm's-law divider, the 8x gain, and f_-3dB = 318.3 Hz (matches the analytic
    1/(2*pi*(Rbe||Ri)*Cin) to 100%, validating the bandwidth budget).
2026-06-10 firmware: RP2040 skeleton + portable C protocol (host-verified, interop-tested)
    proto/epg_proto.{h,c}: protocol codec in portable C (COBS+CRC, builders, parser,
    command decoders), shared by firmware and host. test/: C selftest + a
    cross-language interop test proving the C and Python codecs are byte-for-byte
    compatible in both directions. src/: RP2040 Arduino app skeleton (USB-CDC loop,
    DRDY acquisition, keep-in-range Vs servo, sample-stamped events) + ADS131M08 /
    DAC8568 drivers + board.h + platformio.ini. ADC/DAC register details and
    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
2026-06-10 hardware: single-channel netlist + ERC-clean KiCad schematic capture
    channel_netlist.py: daughtercard as checkable data (23 comp / 71 pins / 21 nets)
    with an ERC-style checker (0 err / 0 warn). gen_kicad_sch.py emits a real
    single_channel.kicad_sch (box symbols + global-label connectivity) from it.
    Validated with kicad-cli (KiCad 10.0.3): upgrade + ERC pass with only benign
    warnings (embedded symbols + 3 intentional single-node nets), zero connectivity
    errors; rendered to SVG/PDF. Boxes/no footprints = first capture for cleanup.
    [single_channel.kicad_sch]
2026-06-10 chore: drop stray KiCad lock file, ignore *.lck
2026-06-10 hardware: PCB layout groundwork + hand-off (footprints, placed board, spec, DRU)
    Assign KiCad footprints (netlist + schematic Footprint properties; 3 PLACEHOLDERs).
    Generate a pre-placed single_channel.kicad_pcb via the pcbnew API (electrometer-aware
    placement, 60x40mm, 4 layers; kicad-cli DRC: 0 structural errors, 40 placement-
    refinement items). Add pcb-layout.md (stackup, guard rings, Cin<=1pF rules, net
    classes, grounding) and single_channel.kicad_dru (custom rules, parse-validated).
    [single_channel.kicad_pcb, single_channel.kicad_sch]
2026-06-10 chore: ignore KiCad DRC report + local .kicad_prl
